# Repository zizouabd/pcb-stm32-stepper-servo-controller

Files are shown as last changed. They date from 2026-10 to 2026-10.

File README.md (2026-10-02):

# 🚀 Contrôleur STM32 - 2x Moteurs Pas-à-Pas (A4988) & 4x Servomoteurs

Ce dépôt contient la conception matérielle complète (schématique et PCB 2 couches $100\text{ mm} \times 100\text{ mm}$) d'une carte de contrôle embarquée pour la robotique et l'automatisme. Elle est pilotée par une **STM32 Black Pill** et alimentée par une batterie **LiPo 3S (12V)**.

---

## 📸 Aperçu du Projet

### 1. Schéma Électrique
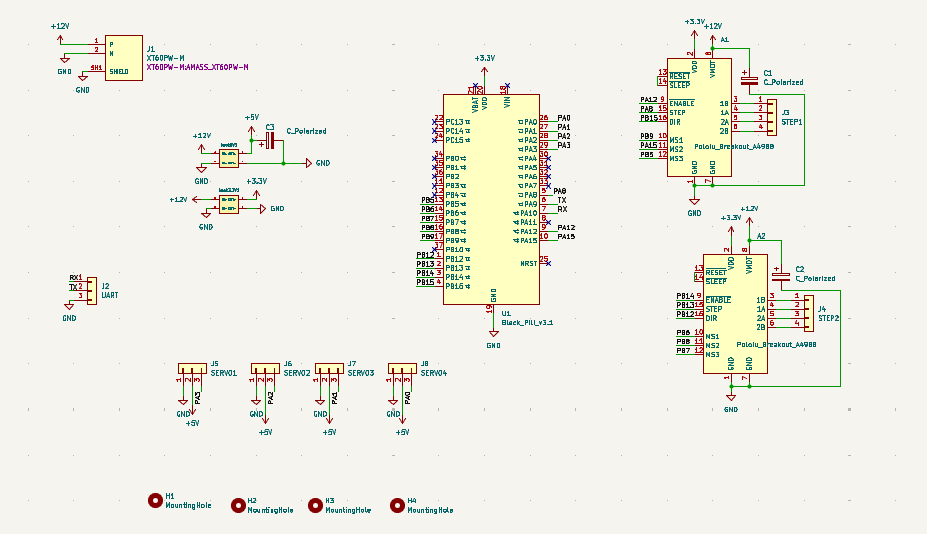
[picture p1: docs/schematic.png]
Schéma Électrique


### 2. Routage PCB (Vue 2D)
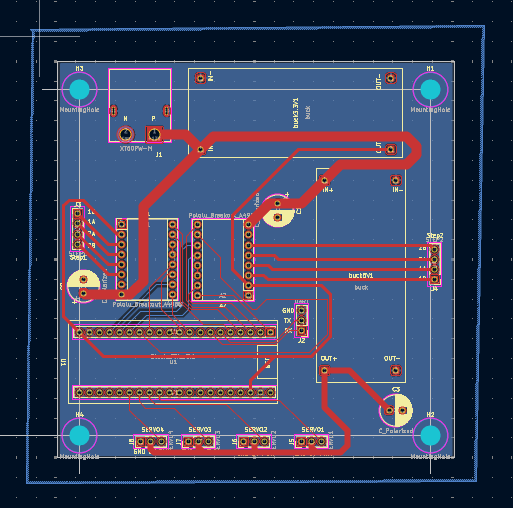
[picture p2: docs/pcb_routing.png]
Routage PCB


### 3. Rendu 3D de la Carte
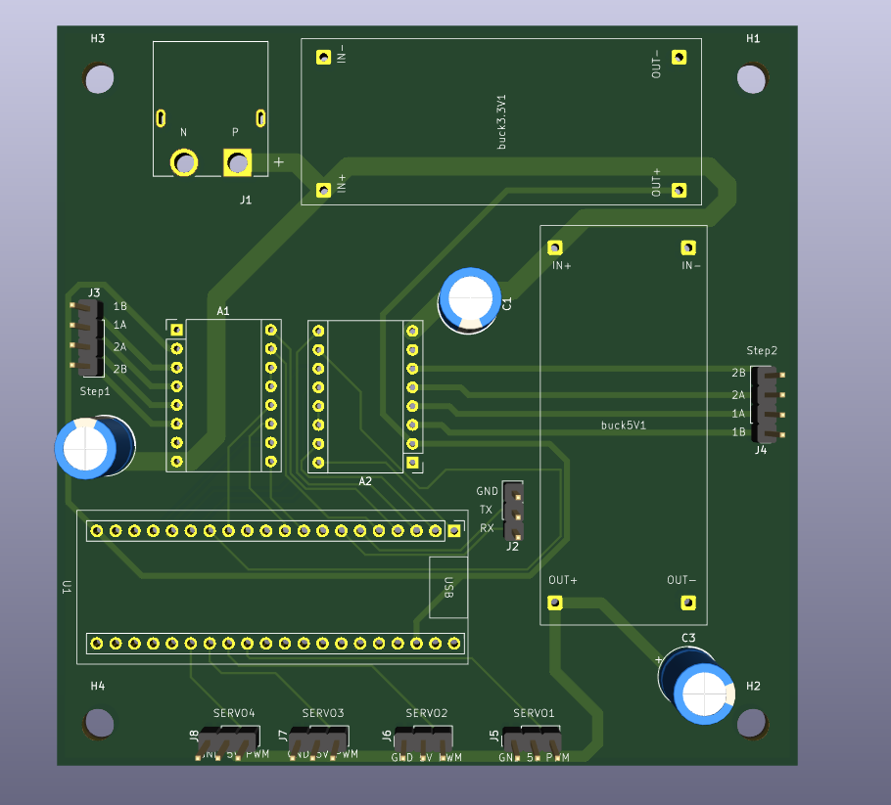
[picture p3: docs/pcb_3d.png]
Rendu 3D PCB


---

## ⚡ Architecture d'Alimentation : La stratégie des "Deux Bucks"

La carte accepte une tension d'entrée principale $12\text{ V}$ via un connecteur **XT60**. Pour garantir une stabilité maximale et isoler les bruits électromécaniques, nous avons fait le choix d'intégrer **deux convertisseurs Buck (DC-DC) distincts** :

### 1. Buck 3.3V (Logique & Microcontrôleur)
* **Rôle :** Alimentation stable du STM32 (broche `VDD`) et des entrées logiques des drivers A4988.
* **Intérêt :** Consommation faible et constante. L'isolation de ce rail protège le processeur contre les chutes de tension (*brownouts*).

### 2. Buck 5V (Puissance Servomoteurs)
* **Rôle :** Alimentation directe des 4 servomoteurs (`J5` à `J8`) et du rail `VIN` de secours.
* **Intérêt :** Absorbe les forts appels de courant et le bruit inductif (*Back-EMF*) générés par les moteurs des servos sans impacter la logique numérique du STM32.

---

## 🔋 Rôle et Placement des Condensateurs de Filtrage ($220\text{ µF}$)

Pour assurer la longévité des composants et la stabilité des tensions, des condensateurs électrolytiques de **$220\text{ µF}$** ont été intégrés aux emplacements stratégiques de la carte :

### 1. Condensateurs sur la ligne `VMOT` des A4988 ($220\text{ µF}$)
Placés au plus près de la broche d'alimentation haute tension (`VMOT`) de chaque driver pas-à-pas :
* **Protection contre les surtensions inductives (Back-EMF) :** Les bobines des moteurs pas-à-pas génèrent de violents pics de tension en retour lors des commutations rapides ou du freinage. Sans ces condensateurs de $220\text{ µF}$, ces transitoires peuvent dépasser la tension maximale tolérée par le A4988 ($35\text{ V}$) et détruire instantanément le driver.
* **Réservoir d'énergie local :** Ils fournissent l'énergie instantanée nécessaire au hachage PWM du courant dans les phases des moteurs, évitant que les pics de courant ne se propagent sur toute la ligne $12\text{ V}$.

### 2. Condensateur en sortie du Buck 5V ($220\text{ µF}$)
Placé immédiatement en sortie du convertisseur $5\text{ V}$ alimentant les servomoteurs :
* **Absorption des pics de démarrage (Inrush Current) :** Un servomoteur peut appeler plusieurs ampères pendant quelques millisecondes lorsqu'il démarre ou change brutalement de sens. Ce condensateur de $220\text{ µF}$ sert de réservoir d'énergie immédiat pour lisser ces appels de courant et éviter l'écroulement de la ligne $5\text{ V}$.
* **Filtrage de l'ondulation (Ripple) :** Il réduit le bruit haute fréquence issu du hachage interne du Buck $5\text{ V}$, garantissant un signal propre pour les servos et l'électronique annexe.

---

## 📐 Création des Empreintes Personnalisées (Custom Footprints)

Afin d'assurer un assemblage parfait et de respecter les dimensions compactes de la carte ($100\text{ mm} \times 100\text{ mm}$), plusieurs empreintes spécifiques ont été créées sur mesure dans une bibliothèque dédiée du projet (`.pretty`) :

* **Modules Buck DC-DC (`buck3.3V1` & `buck5V1`) :** Les modules abaisseurs génériques ne possédant pas de standard de perçage universel, leurs empreintes ont été modélisées manuellement (espacement exact des broches `IN+`, `IN-`, `OUT+`, `OUT-` et dimensions hors-tout) pour s'intégrer directement comme cartes filles.
* **STM32 Black Pill (`Black_Pill_v3.1`) :** Empreinte personnalisée assurant le pitch standard de $2.54\text{ mm}$ entre les rangées de broches et l'intégration exacte du connecteur USB-C.

---

## 🛠️ Contraintes de Fabrication & Règles de Routage (DRC)

Le routage de la carte a été validé sous KiCad avec zéro erreur DRC selon les règles de fabrication industrielles standard :

| Paramètre | Valeur Minimale Validée |
| :--- | :--- |
| **Largeur des pistes de signal** (`STEP`, `DIR`, `SERVO`) | `0.3 mm`  |
| **Largeur des pistes de puissance** (`+5V`, `+12V`, Moteurs) | `0.8 mm` à `2.5 mm` |
| **Isolement entre pistes (Clearance)** | `0.3 mm` |
| **Distance cuivre au bord de carte (Edge.Cuts)** | `0.5 mm` |
| **Plan de masse** | Plan continu sur couche inférieure (`B.Cu`) |

---

## ⚠️ Note Importante : Configuration de la broche PA15 (SWD)

Sur cette carte, la broche **`PA15`** du STM32 est reliée au signal `MS2` du premier driver A4988.

* **Mode de programmation :** Par défaut, `PA15` est réservée à la fonction de débogage JTAG. Pour l'utiliser comme une broche d'entrée/sortie classique (GPIO), la programmation du STM32 **doit impérativement être effectuée en mode SWD (Serial Wire Debug)** via ST-Link (`SWDIO` sur PA13, `SWCLK` sur PA14).

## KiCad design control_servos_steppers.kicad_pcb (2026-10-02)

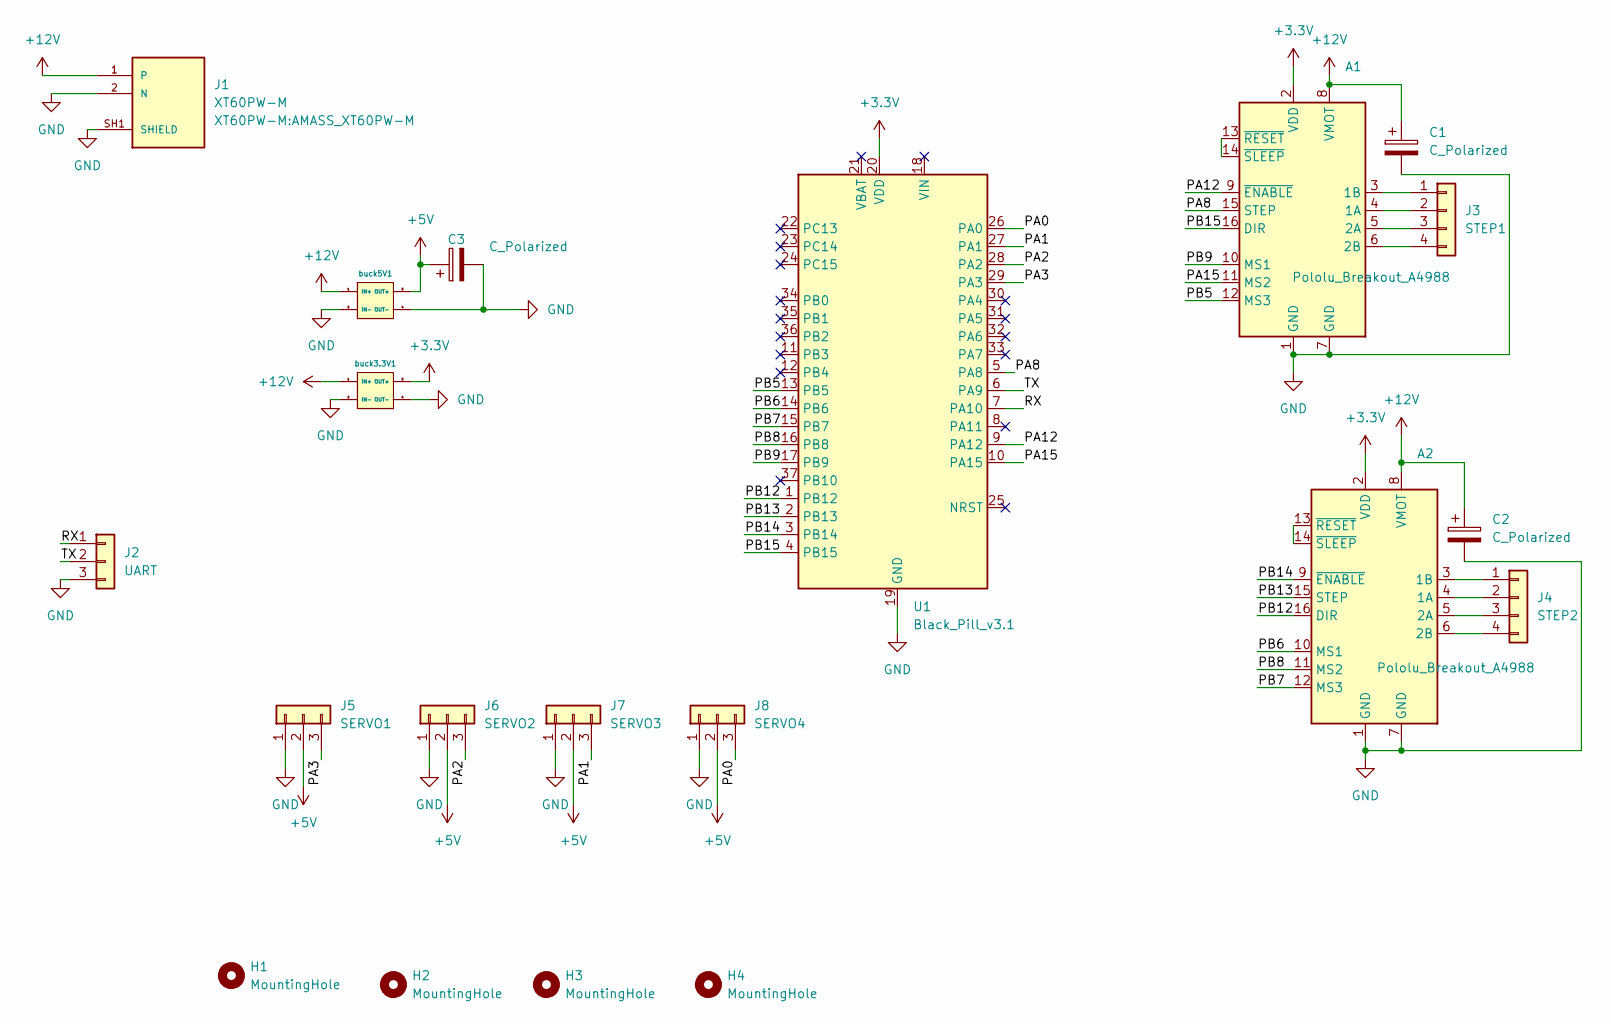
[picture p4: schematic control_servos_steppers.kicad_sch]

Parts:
A1, A2: Pololu_Breakout_A4988; Pololu_Breakout-16_15.2x20.3mm
C1, C2, C3: C_Polarized; CP_Radial_D8.0mm_P3.50mm
H1, H2, H3, H4: MountingHole; MountingHole_4.3mm_M4
J1: XT60PW-M; AMASS_XT60PW-M; PARTREV 1.2
J2: UART; PinHeader_1x03_P2.54mm_Vertical
J3: STEP1; PinHeader_1x04_P2.54mm_Vertical
J4: STEP2; PinHeader_1x04_P2.54mm_Vertical
J5: SERVO1; PinHeader_1x03_P2.54mm_Vertical
J6: SERVO2; PinHeader_1x03_P2.54mm_Vertical
J7: SERVO3; PinHeader_1x03_P2.54mm_Vertical
J8: SERVO4; PinHeader_1x03_P2.54mm_Vertical
U1: Black_Pill_v3.1
buck3.3V1, buck5V1: XL4015 buck module

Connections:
+3.3V: A1.2 (VDD), A2.2 (VDD), U1.20 (VDD), U1.38 (VDD), buck3.3V1.3 (OUT+)
+5V: C3.1, J5.2, J6.2, J7.2, J8.2, buck5V1.3 (OUT+)
+12V: A1.8 (VMOT), A2.8 (VMOT), C1.1, C2.1, J1.1, buck3.3V1.1 (IN+), buck5V1.1 (IN+)
/PA0: J8.3, U1.26 (PA0)
/PA1: J7.3, U1.27 (PA1)
/PA2: J6.3, U1.28 (PA2)
/PA3: J5.3, U1.29 (PA3)
/PA8: A1.15 (STEP), U1.5 (PA8)
/PA12: A1.9 (~ENABLE), U1.9 (PA12)
/PA15: A1.11 (MS2), U1.10 (PA15)
/PB5: A1.12 (MS3), U1.13 (PB5)
/PB6: A2.10 (MS1), U1.14 (PB6)
/PB7: A2.12 (MS3), U1.15 (PB7)
/PB8: A2.11 (MS2), U1.16 (PB8)
/PB9: A1.10 (MS1), U1.17 (PB9)
/PB12: A2.16 (DIR), U1.1 (PB12)
/PB13: A2.15 (STEP), U1.2 (PB13)
/PB14: A2.9 (~ENABLE), U1.3 (PB14)
/PB15: A1.16 (DIR), U1.4 (PB15)
/RX: J2.1, U1.7 (PA10)
/TX: J2.2, U1.6 (PA9)
GND: A1.1 (GND), A1.7 (GND), A2.1 (GND), A2.7 (GND), C1.2, C2.2, C3.2, J1.2 (N), J1.SH1 (SHIELD), J1.SH2 (SHIELD), J2.3, J5.1, J6.1, J7.1, J8.1, U1.19 (GND), U1.39 (GND), buck3.3V1.2 (IN-), buck3.3V1.4 (OUT-), buck5V1.2 (IN-), buck5V1.4 (OUT-)
unnamed: A1.4 (1A), J3.2
unnamed: A1.3 (1B), J3.1
unnamed: A1.5 (2A), J3.3
unnamed: A1.6 (2B), J3.4
unnamed: A1.13 (~RESET), A1.14 (~SLEEP)
unnamed: A2.4 (1A), J4.2
unnamed: A2.3 (1B), J4.1
unnamed: A2.5 (2A), J4.3
unnamed: A2.6 (2B), J4.4
unnamed: A2.13 (~RESET), A2.14 (~SLEEP)

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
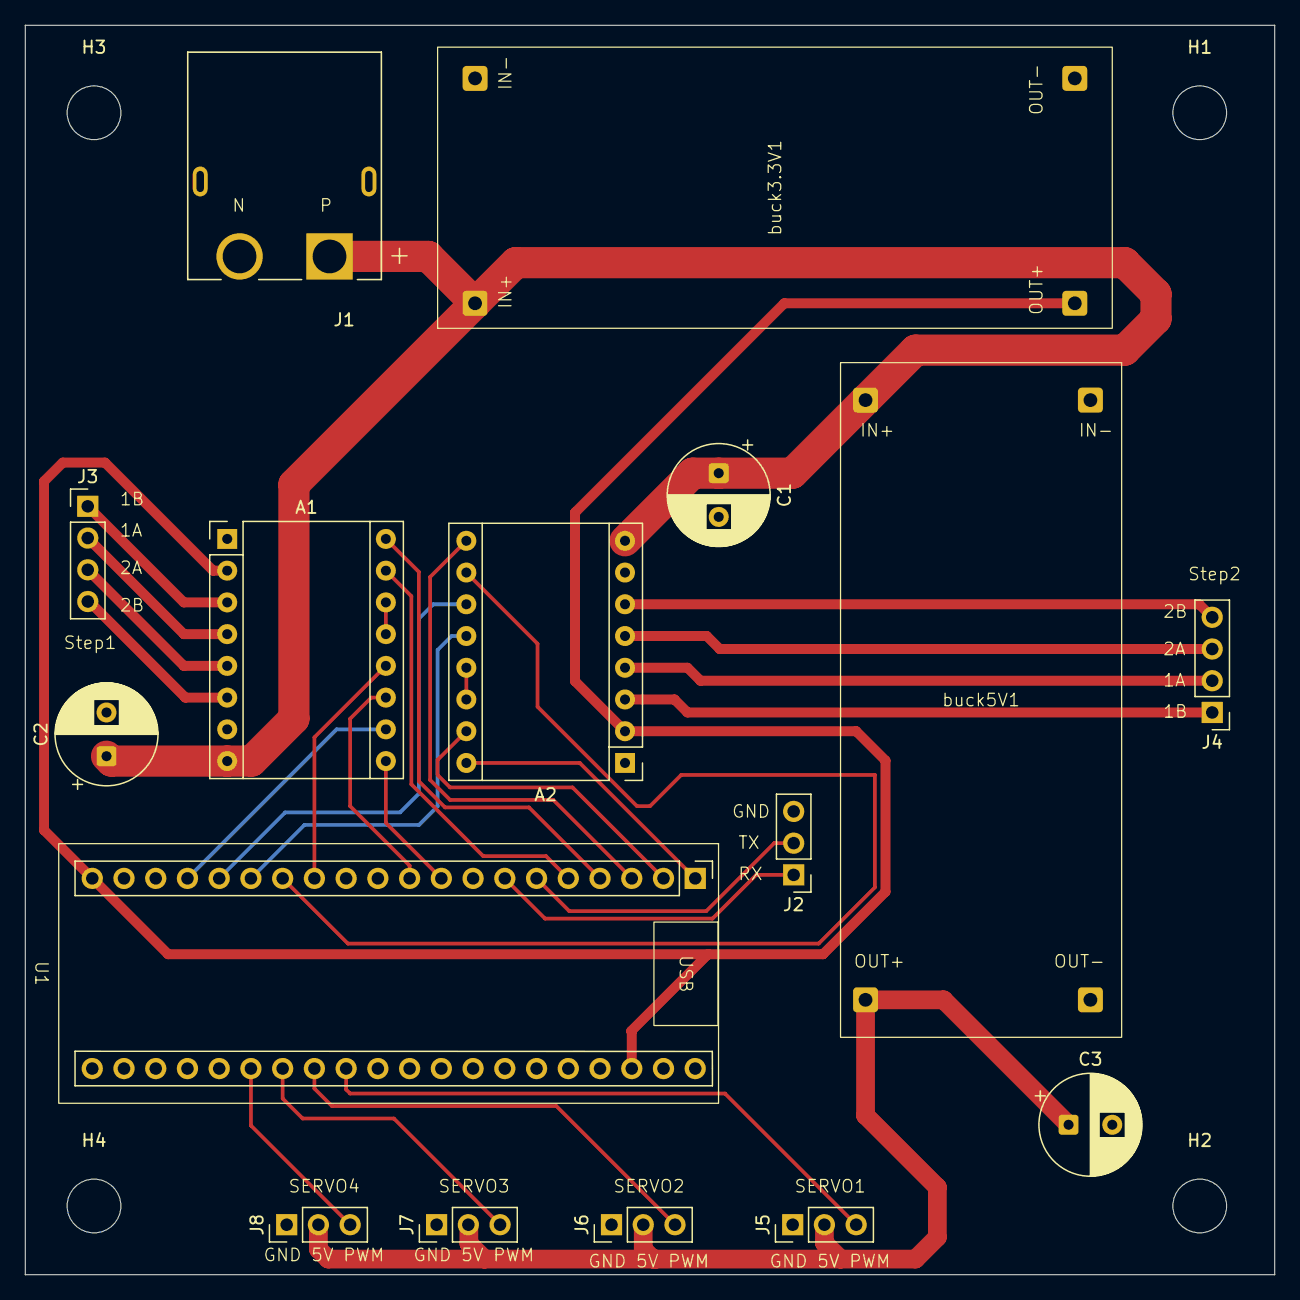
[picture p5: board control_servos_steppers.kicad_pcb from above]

Board: 2 copper layers, 100.0 x 100.0 mm, 20 parts (0 on the bottom side), 32 nets.

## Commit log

2026-10-02 Commit initial : Contrôleur STM32 Black Pill avec A4988 et Servos
    [control_servos_steppers.kicad_pcb, control_servos_steppers.kicad_sch]
2026-10-02 Docs: Ajout du README.md et des visuels
2026-10-02 Docs: Ajout des visuels PNG pour le README
2026-10-02 Fix formatting in signal trace width section
